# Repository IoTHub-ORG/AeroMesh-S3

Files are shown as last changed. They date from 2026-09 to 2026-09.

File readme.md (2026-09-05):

## AeroMesh S3

24bd86d9ffc247108bd2672ff4d77e05

An open-source, autonomous 3D aerial mapping drone controlled directly from a smartphone. AeroMesh S3 eliminates costly proprietary radio transmitters by implementing an onboard ESP32-S3 Wi-Fi MAVLink telemetry bridge, pairing autonomous waypoint navigation with a laser-synchronized downward photogrammetry payload for under $170(₹14,100).

## 1. Project Overview

* **The Problem:** Enterprise aerial surveying systems(such as Wingtra or senseFly) cost upwards of $5k to $ 10k , making photogrammetric mapping inaccessible to students, independent researchers, and small-scale agriculture.

* **The Limitation of Hobby Drones:** Standard DIY quadcopters require an expensive $80+ dedicated radio controller, use upward-tilted cameras suited only for manual racing, and capture uncalibrated video clips rather than structure, geo-referenced spatial data.

* **The Solution:** AeroMesh S3 is a sub-$170 mapping platform that executes automated lawnmower survey grids without a physical RC transmitter. It uses an onboard ESP32-S3 microcontroller to create a local Wi-Fi telemetry bridge, allowing any smartphone running **QGroundControl** to dispatch missons, monitor live metrics, and trigger fail-safes.

## 2. Heterogeneous Dual-Brain Architecture
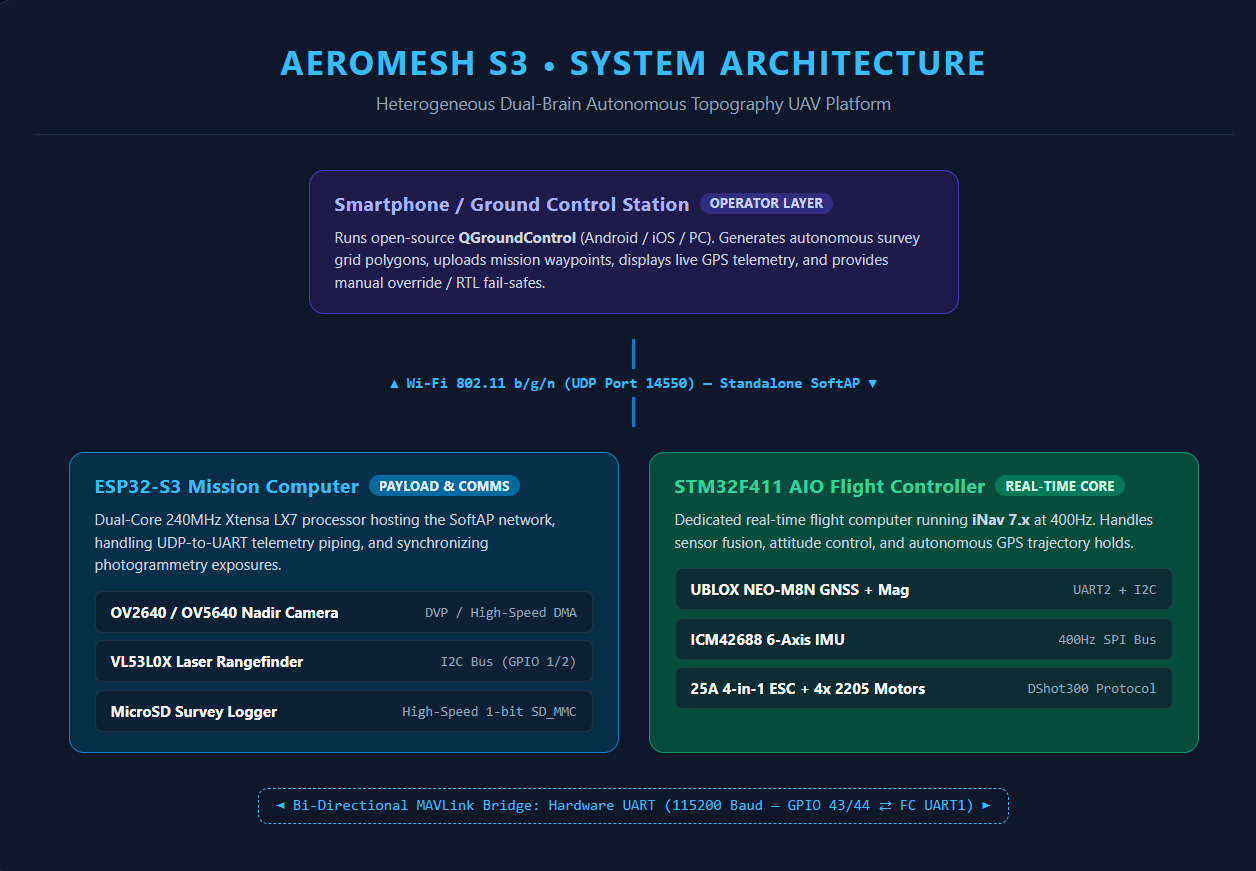
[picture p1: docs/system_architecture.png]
AeroMesh S3 System Architecture

Running flight stabilization loops alongside camera and Wi-Fi streaming on a single microcontroller introduces RTOS thread latency and task contention. AeroMesh S3 separates flight stabilization from mission compute across two dedicated microcontrollers:

```text 
[Smartphone/ Ground Control Station]
          |
          |
          |
          ▼
[Mission Computer: ESP32-S3]
          |────MicroSD Card (High-speed SPI: Stores JPEG frames and CSV spatial logs)
          |────VL53L0X Laser Rangefinder (I2C: Measures real-time ground clearance)
          |
          |────Hardware UART(115200 Baud- bi-directional MAVLink Bridge)
          ▼
[Flight Controller: STM32F411 AIO]
          |────UBLOX NEO-M8N GPS + Compass(Autonomous waypoint navigation)
          |────ICM42688 IMU( 400Hz real-time attitude stabilization via iNav)
          |
          └──── 25A 4-in-1 ESC + 4X 2205 Brushless Motors
```

* **The Real-Time Brain (STM32F411):** Runs iNav flight firmware, dedicating all compute cycles to sensor filtering, attitude stabilization, and motor drive via DShot protocols.
* **The Mission Brain (ESP32-S3):** Broadcasts a local Wi-Fi Access Point, routes MAVLink telemetry packets to QGroundControl, triggers the downward camera, and logs distance data from the laser sensor.
-------

## 3. Ground Control and Smartphone Connection

1. **Standalone Wi-Fi Hotspot:** The ESP32-S3 chip broadcasts a local Wi-Fi network after boot. There is no need for any router, mobile internet, or cellular towers.

2. **QGroundControl Integration:** You have to connect your mobile device or laptop to the drone's Wi-Fi and open the open-source **QGroundControl** app. It creates a connection over UDP port 14550.

3. **Autonomous Grid Survey:** In QGroundControl, select the Survey Tool and draw a polygon over the survey area. The app calculates flight lines with a 75% photo overlap sideways and forwards. To arm the drone, click or tap on **"Upload & Start Mission"**, the drone arms itself and performs the survey autonomously returning to the launch point.

4. **Emergency Controls & Fail-Safes:** The bi-directional telemetry is maintained by the ground station. A single tap to the screen triggers **Return to Launch (RTL)**, instructing the flight controller to fly back to the base using GPS and land safely. Virtual touch joystick and proper emergency motor-kill controls are also present.

## 4. Data Pipeline & 3D Reconstruction

During autonomous flight, the ESP32-S3 triggers the downward camera every 4 meters of horizontal movement and reads the VL53L0X micro-LiDAR to record the exact distance to the ground. Each entry is saved to the onboard MicroSD card:

```csv
Frame_ID,Timestamp_ms,Latitude,Longitude,Baro_Altitude_m,Laser_AGL_mm
IMG_0001.JPG,124820,26.84671,80.94612,20.40,19820
IMG_0002.JPG,126840,26.84674,80.94618,20.35,19790
```

### What Happens with the Captured Data?
After landing of the drone, the MicroSD cards is plugged to a pc using either WebODM or Gaussian Splatting tool:

* **3D Models (`.obj`/ `.ply`):** The software generates a high-resolution 3D polygon mesh that can be used to build a game level and or/ an architectural model in Blender, Unity, or Unreal Engine.

* **Digital Elevation Model (DEM):** Colorized topographic elevation maps shows erosion, slopes, and zones that contain pooling water.

* **Volumetric Analysis:** This feature can calculate the volume of gravel, compost, soil etc. It can also find the volume of soil that was excavated. It does not require field surveying and can be done on a computer.

---

## 5. Hardware Specifications & Bill of Materials

All components are verified in-stock from authorized domestic Indian suppliers (Robu.in / JLCPCB) with 18% GST included:

| Component Category | Exact Hardware Specification | Supplier | Cost (INR) | Cost (USD) |
| :--- | :--- | :--- | :---: | :---: |
| **Airframe** | Mark4 5-inch 3K Carbon Fiber Quadcopter Frame | Robu.in | ₹1,199 | $14.32 |
| **Motors** | ReadyToSky RS2205 2300KV Brushless Motors (Set of 4) | Robu.in | ₹3,200 | $38.21 |
| **Flight Stack** | JHEMCU GHF411AIO Pro 25A F4 2-4S AIO Flight Controller + ESC | Robu.in | ₹3,999 | $47.75 |
| **GNSS & Compass** | UBLOX NEO-M8N GPS Module with Active Ceramic Antenna | Robu.in | ₹1,399 | $16.70 |
| **Flight Battery** | Orange 3S 1500 mAh 40C/50C LiPo Battery Pack (XT60) | Robu.in | ₹1,150 | $13.73 |
| **Balance Charger** | B3 Pro 10W 2S-3S Compact Balance Charger | Robu.in | ₹450 | $5.37 |
| **Propellers** | Gemfan 5045 3-Blade Polycarbonate Propellers (2 Pairs) | Robu.in | ₹250 | $2.99 |
| **Vision & Compute**| ESP32-S3-CAM Development Board with OV2640 + MicroSD Slot | Robu.in | ₹999 | $11.93 |
| **LiDAR Altimeter** | VL53L0X Time-of-Flight Micro-LiDAR Distance Sensor | Robu.in | ₹380 | $4.54 |
| **Carrier Shield** | Custom 2-Layer Interconnect Board (5 pcs batch) | JLCPCB | ₹650 | $7.76 |
| **Wiring & Hardware**| XT60 lead, M2/M3 nylon standoffs, 1000 µF Cap, wires | Robu.in | ₹350 | $4.18 |
| **Total System Cost** | **Complete Autonomous 3D Topography Drone** | — | **₹14,026** | **$167.47** |

---

## 6. Electrical Pinout and Wiring

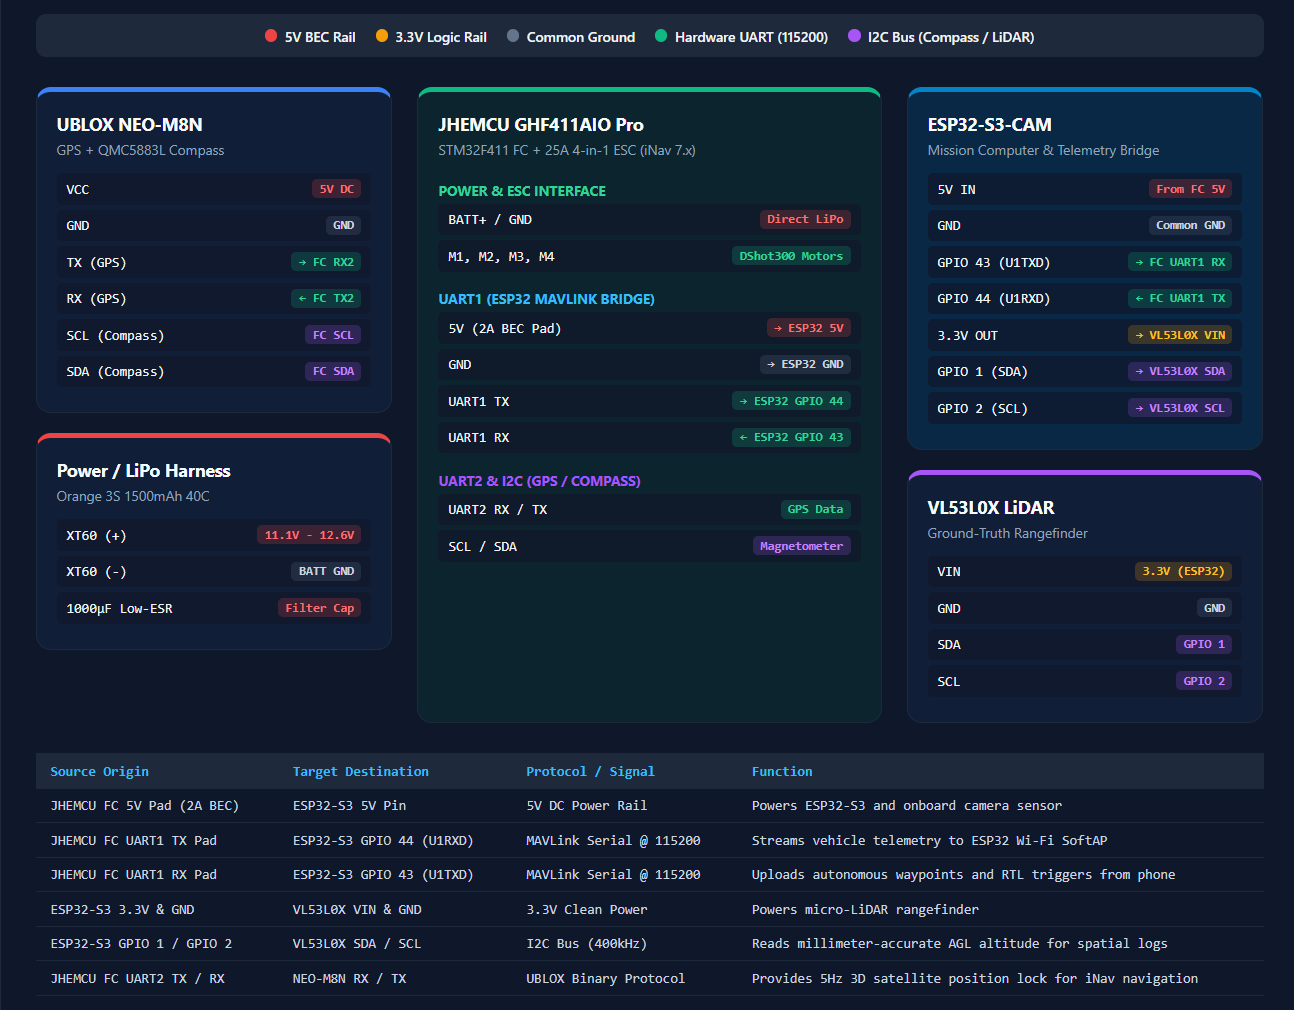
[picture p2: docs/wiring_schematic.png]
AeroMesh S3 Electrical Wiring Schematic


### Flight Controller(STM32F411) to ESP32-S3-CAM:
* `FC 5V(2A BEC Pad)` $\rightarrow$ `ESP32 5V`
* `FC GND` $\rightarrow$ `ESP32 GND`
* `FC UART1 RX` $\rightarrow$ `ESP32 GPIO 43(U1TXD)`
* `FC UART1 TX` $\rightarrow$ `ESP32 GPIO 44(U1RXD)`

### ESP32-S3-CAM to VL53L0X Time-of-Flight Sensor
* `ESP32 3.3V` $\rightarrow$ `VL53L0X VIN`
* `ESP32 GND` $\rightarrow$ `VL53L0X GND`
* `ESP32 GPIO 1` $\rightarrow$ `VL53L0X SDA`
* `ESP32 GPIO 2` $\rightarrow$ `VL53L0X SCL`

### Flight Controller to UBLOX NEO-M8N GPS
* `FC 5V` $\rightarrow$ `GPS VCC`
* `FC GND` $\rightarrow$ `GPS GND`
* `FC UART2 RX` $\rightarrow$ `GPS TX`
* `FC UART2 TX` $\rightarrow$ `GPS RX`
* `FC SCL / SDA` $\rightarrow$ `Compass SCL / SDA`

---

## 7.Repository Structure
```text
|
├──data/
|  └──sample_survey_log.csv   # Validated spatial survey log (frames & LiDAR AGL)
|
├──docs/
|    ├──system_architecture.png    # Dual-brain architecture block diagram
|    └──wiring_schematic.png       # Complete pin-to-pin wiring diagram
|
├──firmware/
|     ├──esp32_mavlink_bridge/  #SoftAP & UDP-to-UART bridge script
|     |  └──esp32_mavlink_bridge.ino
|     ├──survey_logger/         #Camera capture & ToF laser logger loop
|     |  └──surevey_logger.ino
|     └──inav_cli_diff.txt
|
├──hardware/
|   ├──3d_mounts/
|   |  ├── camera_lidar_nadir_mount.scad  # Editable OpenSCAD source (Nadir mount)
|   |  ├── camera_lidar_nadir_mount.stl
|   |  ├── landing_skid_leg.scad     # Editable OpenSCAD source (35mm landing skids)
|   |  └──landing_skid_leg.stl     ## 35mm ground-clearance arm skid
|   ├──carrier_shield/             # Gerber production files for interconnect PCB
|   └──BOM.md          # Detailed parts breakdown & supplier links    
└── README.md
```   

## 8. Setup & Build Order

1. **Firmware Installation:** Install firmware iNav 7.x for STM32F411 AIO. Set `UART1` for 115200 baud-rate communication of MAVLink telemetry, set `UART2` for UBLOX GPS communication.

2. **ESP32 Bridge Installation:** Upload `firmware/esp32_mavlink_bridge` firmware to ESP32-S3 via Arduino IDE / PlatformIO in order to create an independent UDP-to-UART channel.

3. **Bench Verification:** Test sensor synchronization over USB. Ensure that triggering a capture writes a test frame and matching laser distance to the MicroSD memory.

4. **Mechanical Assembly:** Assemble the 2205 motors and 4-in-1 ESC to the Mark4 frame. Connect optical and laser sensors in the vibration-resistant mount located at the bottom of the quadcopter.

5. **Calibration and Flight in the Field:** Calibrate the compass in the absence of magnetic field influence, get 3D GPS satellite position lock, and send out a survey grid in QGroundControl application on your phone.

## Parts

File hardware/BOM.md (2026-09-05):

# Bill of Materials (BOM) — AeroMesh S3

All pricing is verified with 18% GST included from authorized domestic suppliers (Robu.in / JLCPCB).

| Category | Component Description | Supplier | Cost (INR) | Cost (USD) |
| :--- | :--- | :--- | :---: | :---: |
| **Airframe** | Mark4 5-inch 3K Carbon Fiber Quadcopter Frame | Robu.in | ₹1,199 | $14.32 |
| **Propulsion** | ReadyToSky RS2205 2300KV Brushless Motors (Set of 4) | Robu.in | ₹3,200 | $38.21 |
| **Avionics** | JHEMCU GHF411AIO Pro 25A F4 2-4S AIO Flight Controller + ESC | Robu.in | ₹3,999 | $47.75 |
| **Navigation** | UBLOX NEO-M8N GPS Module with Active Ceramic Antenna | Robu.in | ₹1,399 | $16.70 |
| **Power** | Orange 3S 1500 mAh 40C/50C LiPo Battery Pack (XT60) | Robu.in | ₹1,150 | $13.73 |
| **Charger** | B3 Pro 10W 2S-3S Compact LiPo Balance Charger | Robu.in | ₹450 | $5.37 |
| **Propellers** | 2 Pairs Gemfan 5045 3-Blade Polycarbonate Propellers | Robu.in | ₹250 | $2.99 |
| **Vision/Compute** | ESP32-S3-CAM Development Board (OV2640/OV5640 + MicroSD) | Robu.in | ₹999 | $11.93 |
| **Altimeter** | VL53L0X Time-of-Flight Micro-LiDAR Distance Sensor | Robu.in | ₹380 | $4.54 |
| **Shield/Wiring** | Custom Interconnect Carrier Shield (5 pcs fab) | JLCPCB | ₹650 | $7.76 |
| **Accessories** | XT60 lead, M2/M3 nylon standoffs, 1000 µF capacitor, wiring | Robu.in | ₹350 | $4.18 |
| **Total** | **Complete Autonomous 3D Topography Mapping System** | — | **₹14,026** | **$167.47** |

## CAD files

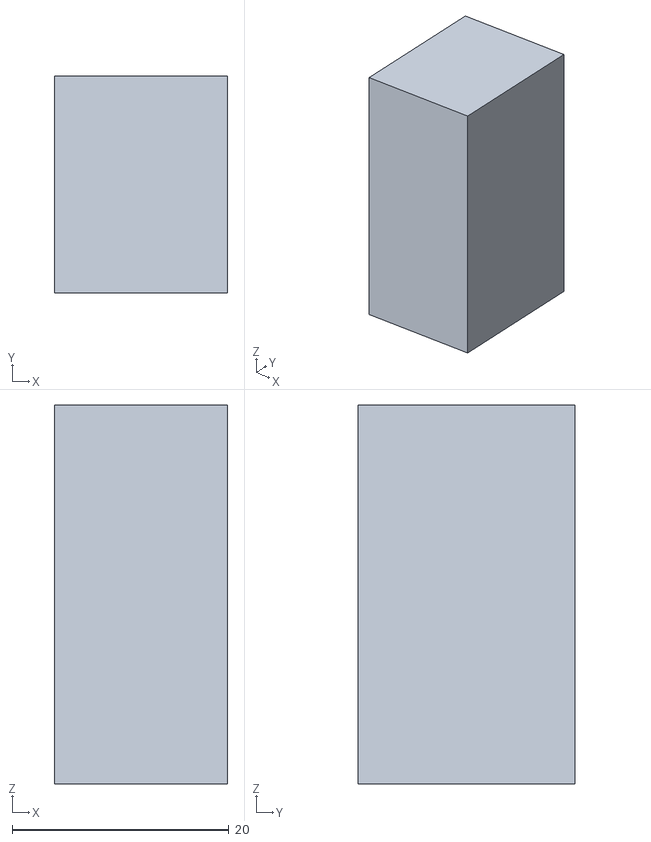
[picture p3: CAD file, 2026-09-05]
hardware/3d_mounts/landing_skid_leg.stl
16.0 x 20.0 x 35.0

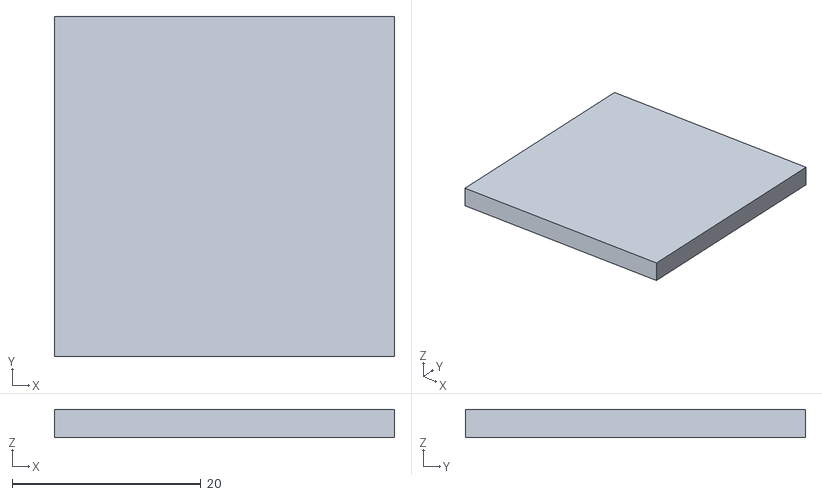
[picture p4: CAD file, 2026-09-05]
hardware/3d_mounts/camera_lidar_nadir_mount.stl
36.0 x 36.0 x 3.00

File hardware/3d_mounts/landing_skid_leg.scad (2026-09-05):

// AeroMesh S3 - 35mm Elevated TPU Landing Skid
// Material: TPU (Flexible 95A)
// Mount: Mark4 Motor Arm Extrusion

$fn = 60;

skid_height = 35;
arm_width = 16;
arm_length = 20;
wall_thickness = 3;

difference() {
    // Outer landing foot body
    cube([arm_width, arm_length, skid_height], center = false);

    // Motor arm slot
    translate([wall_thickness, -1, skid_height - 10])
        cube([arm_width - (2 * wall_thickness), arm_length + 2, 11], center = false);

    // Zip-tie fastening channel
    translate([-1, arm_length / 2, skid_height - 5])
        rotate([0, 90, 0])
        cylinder(h = arm_width + 2, r = 1.5, center = false);
}

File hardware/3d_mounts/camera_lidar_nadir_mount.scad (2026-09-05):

// AeroMesh S3 - Nadir Camera & VL53L0X LiDAR Mount
// Material: PLA / PETG / TPU
// Platform: 36x36mm Mark4 Bottom Plate Mount

$fn = 60;

plate_width = 36;
plate_length = 36;
plate_thickness = 3;
m3_hole_r = 1.6;

difference() {
    cube([plate_width, plate_length, plate_thickness], center = true);

    translate([15, 15, 0]) cylinder(h = plate_thickness +2, r = m3_hole_r, center = true);
    translate([-15, 15, 0]) cylinder(h = plate_thickness +2, r = m3_hole_r, center = true);
    translate([15, -15, 0]) cylinder(h = plate_thickness + 2, r = m3_hole_r, center = true);
    translate([-15, -15, 0]) cylinder(h = plate_thickness + 2, r = m3_hole_r, center = true);

    cylinder(h = plate_thickness +2, r = 5.0, center = true);

    translate([0, 10, 0]) cube([8, 12, plate_thickness +2], center = true);


}

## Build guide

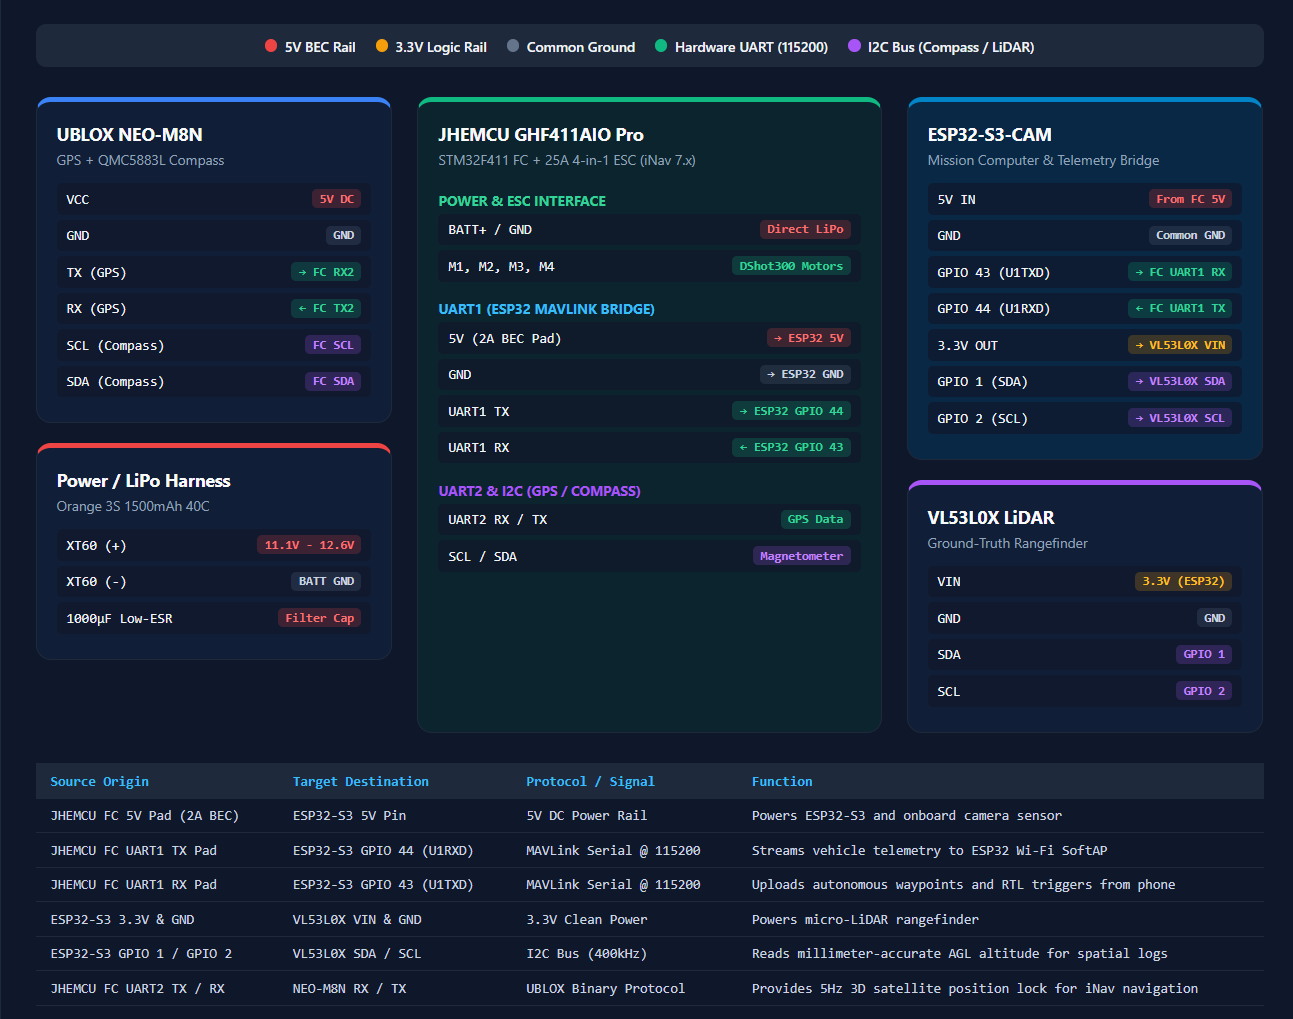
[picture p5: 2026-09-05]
wiring_schematic.png

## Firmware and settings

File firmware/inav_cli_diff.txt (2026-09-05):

# ====================================================================
# iNav 7.x CLI Diff Configuration — AeroMesh S3
# Target: JHEMCU GHF411AIO Pro (STM32F411)
# Architecture: Dual-Brain UAV with ESP32-S3 MAVLink Telemetry Bridge
# ====================================================================

# Mixer Configuration (5-inch Quad X)
mixer QUADX

# Feature Flags
feature -SOFTSERIAL
feature MOTOR_STOP
feature GPS
feature TELEMETRY
feature PWM_OUTPUT_ENABLE
feature AIRMODE

# Serial Port Mapping
# UART1 (Serial 0): MAVLink Telemetry Bridge to ESP32-S3 @ 115200 Baud
# 2 = FUNCTION_TELEMETRY_MAVLINK
serial 0 2 115200 115200 115200 115200

# UART2 (Serial 1): UBLOX NEO-M8N GPS Module @ 115200 Baud
# 2048 = FUNCTION_GPS
serial 1 2048 115200 115200 115200 115200

# Sensor Hardware and Alignment
set gyro_hardware = ICM42688
set align_gyro = DEFAULT
set acc_hardware = ICM42688
set align_acc = DEFAULT
set mag_hardware = AUTO
set align_mag = CW270FLIP
set baro_hardware = BMP280

# Motor and ESC Protocol
set motor_pwm_protocol = DSHOT300
set looptime = 1000
set gyro_sync = ON

# GNSS & Positioning Configuration
set gps_provider = UBLOX
set gps_sbas_mode = AUTO
set gps_auto_config = ON
set gps_auto_baud = ON
set gps_ubx_nav_hz = 5
set gps_min_sats = 6

# Autonomous Navigation & Fail-Safe Parameters
set nav_user_control_mode = ATTI
set nav_auto_speed = 400
set nav_auto_climb_rate = 300
set nav_manual_speed = 500
set nav_mc_bank_angle = 30

# Emergency Return-to-Launch (RTL) Logic
set failsafe_procedure = RTH
set nav_rth_climb_first = ON
set nav_rth_altitude = 2500
set nav_rth_abort_threshold = 50000

save

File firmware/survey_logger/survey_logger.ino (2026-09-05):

#include "esp_camera.h"
#include "FS.h"
#include "SD_MMC.h"
#include<Wire.h>
#include <Adafruit_VL53L0X.h>


#define PWDN_GPIO_NUM     -1
#define RESET_GPIO_NUM    -1
#define XCLK_GPIO_NUM      10
#define SIOD_GPIO_NUM      21
#defince SIOC_GPIO_NUM     14

#define Y9_GPIO_NUM       11
#defince Y8_GPIO_NUM       9
#define Y7_GPIO_NUM        8
#define Y6_GPIO_NUM        6
#define Y5_GPIO_NUM        4
#define Y4_GPIO_NUM        5
#defince Y3_GPIO_NUM       3
#define Y2_GPIO_NUM       13

#define VSYNC_GPIO_NUM    12
#define HREF_GPIO_NUM      7
#define PCLK_GPIO_NUM     15

#define I2C_SDA 1
#define I2C_SCL 2

Adafruit_VL53L0X lox = Adafruit_VL53L0X();

unsigned long imageIndex = 0;
unsigned long lastCapturemillis = 0;
const unsigned long captureIntervalMillis = 15000; // Capture image every 1.5 seconds

bool sdAvailable = false;
bool sensorAvailable = false;


void initCamera() {
    camera_config_t config;
    config.ledc_channel = LEDC_CHANNEL_0;
    config.ledc_timer = LEDC_TIMER_0;
    config.pin_d0 = Y2_GPIO_NUM;
    config.pin_d1 = Y3_GPIO_NUM;
    config.pin_d2 = Y4_GPIO_NUM;
    config.pin_d3 = Y5_GPIO_NUM;
    config.pin_d4 = Y6_GPIO_NUM;
    config.pin_d5 = Y7_GPIO_NUM;
    config.pin_d6 = Y8_GPIO_NUM;
    config.pin_d7 = Y9_GPIO_NUM;
    config.pin_xclk = XCLK_GPIO_NUM;
    config.pin_pclk = PCLK_GPIO_NUM;
    config.pin_vsync = VSYNC_GPIO_NUM;
    config.pin_href = HREF_GPIO_NUM;
    config.pin_sscb_sda = SIOD_GPIO_NUM;
    config.pin_sscb_scl = SIOC_GPIO_NUM;
    config.pin_pwdn = PWDN_GPIO_NUM;
    config.pin_reset = RESET_GPIO_NUM;
    config.xclk_freq_hz = 20000000;
    config.pixel_format = PIXFORMAT_JPEG;


    if(psramFound()){
        config.frame_size = FRAMESIZE_UXGA;
        config.jpeg_quality = 10;
        config.fb_count = 2;
    } else {
        config.frame_size = FRAMESIZE_SVGA;
        config.jpeg_quality = 12;
        config.fb_count = 1;
    }

    esp_err_t err = esp_camera_init(&config);
    if (err != ESP_OK) {
        Serial.printf("Camera init failed with error 0x%x", err);
        
    } else {
        Serial.println("Camera initialized successfully");
    }
}
void initMicroSD() {
  if (!SD_MMC.begin("/sdcard", true)) {
    Serial.println("[ERROR] MicroSD card mount failed.");
    sdAvailable = false;
    return;
  }

  uint8_t cardType = SD_MMC.cardType();
  if (cardType == CARD_NONE) {
    Serial.println("[ERROR] No MicroSD card attached.");
    sdAvailable = false;
    return;
  }

  sdAvailable = true;
  Serial.printf("[OK] MicroSD card mounted. Capacity: %lluMB\n", SD_MMC.cardSize() / (1024 * 1024));

  // Initialize CSV metadata header if log file doesn't exist
  if (!SD_MMC.exists("/survey_log.csv")) {
    File logFile = SD_MMC.open("/survey_log.csv", FILE_WRITE);
    if (logFile) {
      logFile.println("Frame_ID,Timestamp_ms,Laser_AGL_mm,Laser_Status");
      logFile.close();
      Serial.println("[OK] Created new survey_log.csv header.");
    }
  }
}

void initLaserSensor() {
  Wire.begin(I2C_SDA, I2C_SCL);
  
  if (!lox.begin(VL53L0X_I2C_ADDR, false, &Wire)) {
    Serial.println("[WARN] VL53L0X micro-LiDAR not detected on I2C bus.");
    sensorAvailable = false;
  } else {
    sensorAvailable = true;
    // Set high accuracy mode for ground truth measurement
    lox.setMeasurementTimingBudgetMicroSeconds(30000);
    Serial.println("[OK] VL53L0X micro-LiDAR initialized.");
  }
}

void setup() {
  Serial.begin(115200);
  delay(1000);

  Serial.println("\n--- AeroMesh S3 Survey Payload Initializing ---");

  initLaserSensor();
  initMicroSD();
  initCamera();

  Serial.println("--- Setup Complete. Starting Autonomous Capture Loop ---\n");
}

void loop() {
  unsigned long currentMillis = millis();

  if (currentMillis - lastCaptureMillis >= captureIntervalMs) {
    lastCaptureMillis = currentMillis;

  
    uint16_t groundDistanceMm = 0;
    uint8_t rangeStatus = 4; // 4 = out of range / error

    if (sensorAvailable) {
      VL53L0X_RangingMeasurementData_t measure;
      lox.rangingTest(&measure, false);
      rangeStatus = measure.RangeStatus;
      if (rangeStatus != 4) {
        groundDistanceMm = measure.RangeMilliMeter;
      }
    }

    camera_fb_t *fb = esp_camera_fb_get();
    if (!fb) {
      Serial.println("[ERROR] Failed to capture camera frame buffer.");
      return;
    }

    char fileName[32];
    sprintf(fileName, "/IMG_%04lu.JPG", ++imageIndex);

    if (sdAvailable) {
      File imgFile = SD_MMC.open(fileName, FILE_WRITE);
      if (imgFile) {
        imgFile.write(fb->buf, fb->len);
        imgFile.close();
        Serial.printf("[SAVED] %s (%u bytes) | Laser AGL: %u mm\n", fileName, fb->len, groundDistanceMm);
      } else {
        Serial.printf("[ERROR] Failed to open %s on MicroSD for write.\n", fileName);
      }

      File logFile = SD_MMC.open("/survey_log.csv", FILE_APPEND);
      if (logFile) {
        logFile.printf("%s,%lu,%u,%u\n", fileName, currentMillis, groundDistanceMm, rangeStatus);
        logFile.close();
      }
    } else {
      Serial.printf("[DRY-RUN] Captured %s (No SD card present) | Laser: %u mm\n", fileName, groundDistanceMm);
    }

    // Return the frame buffer back to the camera driver pool
    esp_camera_fb_return(fb);
  }
}

}

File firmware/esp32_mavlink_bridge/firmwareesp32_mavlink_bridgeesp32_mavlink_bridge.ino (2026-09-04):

#include <WiFi.h>
#include <WiFiUdp.h>

// Wi-Fi Access Point Configuration
const char *ssid = "AeroMesh-UAV";
const char *password = "aeromesh2026";

// MAVLink UDP Port (Standard QGroundControl port)
const unsigned int localUdpPort = 14550;
IPAddress remoteIP;
unsigned int remotePort = 0;
bool clientConnected = false;

WiFiUDP udp;

// Hardware Serial2 for STM32F411 Flight Controller connection
#define FC_SERIAL Serial2
#define RX_PIN 44 // Connect to FC UART1 TX
#define TX_PIN 43 // Connect to FC UART1 RX

void setup() {
  Serial.begin(115200);
  FC_SERIAL.begin(115200, SERIAL_8N1, RX_PIN, TX_PIN);

  // Set up standalone SoftAP
  WiFi.mode(WIFI_AP);
  WiFi.softAP(ssid, password);
  
  Serial.println("\n--- AeroMesh S3 Telemetry Bridge Online ---");
  Serial.print("Access Point SSID: ");
  Serial.println(ssid);
  Serial.print("Host IP: ");
  Serial.println(WiFi.softAPIP());

  udp.begin(localUdpPort);
  Serial.printf("Listening on UDP port %d\n", localUdpPort);
}

void loop() {
  // 1. Read incoming MAVLink packets from QGroundControl over UDP and forward to FC
  int packetSize = udp.parsePacket();
  if (packetSize > 0) {
    remoteIP = udp.remoteIP();
    remotePort = udp.remotePort();
    clientConnected = true;

    uint8_t udpBuffer[512];
    int len = udp.read(udpBuffer, sizeof(udpBuffer));
    if (len > 0) {
      FC_SERIAL.write(udpBuffer, len);
    }
  }

  // 2. Read telemetry stream from Flight Controller and pipe back to QGroundControl
  if (FC_SERIAL.available() && clientConnected) {
    uint8_t serialBuffer[512];
    int bytesRead = 0;
    while (FC_SERIAL.available() && bytesRead < sizeof(serialBuffer)) {
      serialBuffer[bytesRead++] = FC_SERIAL.read();
    }
    udp.beginPacket(remoteIP, remotePort);
    udp.write(serialBuffer, bytesRead);
    udp.endPacket();
  }
}

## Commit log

2026-09-04 docs: add ground control workflow and fix architecture formatting
2026-09-05 docs: update README, finalize sub- BOM, and update MAVLink firmware
2026-09-05 docs: complete wiring pinout in README and clean up BOM table
2026-09-05 docs: finalize README sections, fix telemetry typos, and add CSV log sample
2026-09-05 feat: add 3D camera-lidar mount STL and architecture diagram to docs
    [camera_lidar_nadir_mount.stl]
2026-09-05 docs: add visual wiring schematic, iNav CLI config, and sample survey dataset
    [inav_cli_diff.txt, sample_survey_log.csv]
2026-09-05 feat: add 35mm elevated TPU landing skid CAD model
    [landing_skid_leg.stl]
2026-09-05 feat: add editable OpenSCAD source files for sensor mount and landing skid
    [camera_lidar_nadir_mount.scad, landing_skid_leg.scad]
2026-09-05 docs: update README tree with editable OpenSCAD CAD sources
